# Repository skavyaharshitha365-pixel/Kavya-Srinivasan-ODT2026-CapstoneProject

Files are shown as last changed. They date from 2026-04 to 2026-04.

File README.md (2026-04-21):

Arcade Games

An interactive floor-based arcade gaming system featuring a 3×3 grid of illuminated,
pressure-sensitive tiles synchronized with overhead visual effects. Players engage in four
different games (DDR-style rhythm, Memory sequence, Whack-a-Mole reflexes, and Tic-Tac-Toe
strategy) through physical movement while disco lights, lasers, and mechanical motors create
an immersive atmosphere.

Kavya Harshitha Srinivasan
Awanti Phadke

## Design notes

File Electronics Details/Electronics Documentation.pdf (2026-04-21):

# Electronics Documentation

### 1. Electronics Block Diagram

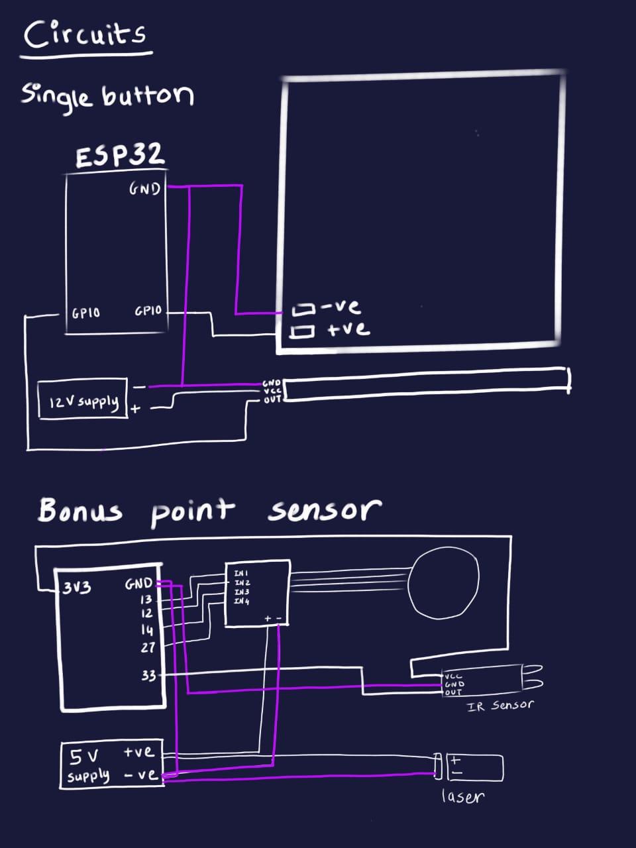
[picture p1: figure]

### 2. Components Table

Component | Quantity | Purpose | Justification
Stepper Motor | 2 | To move the Lasers for hand indications | Complete rotation is required for this application and hence stepper motor
Neopixel Strip | 10 | To give visual cues and feedback on the tiles and set the ambience in overhead disco | Bright multi color lights are required for clear indication for where to step
Laser pointers | 2 | To indicate location of IR sensor and to set the ambience
Bread board | 3
Power module | 2
IR Sensors | 2 | To detect the hands | Small with adjustable range
Copper wire | 10m approx
Electronic Tape | 3m | Hold wires and connections in place and

Power module Adapter | 3
DC Adapter | 2 | Connect 12V neopixel strips

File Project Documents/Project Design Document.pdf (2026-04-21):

## Interactive Arcade System with Physical Tile Grid

## 1. Design Intent

A full-scale arcade installation that transforms digital games into physical experiences. Players step onto a 3×3 grid of illuminated floor tiles, surrounded by overhead disco lighting effects, laser mood lighting and gaming, and motorized visual indicators. Each game (DDR-style rhythm, Memory, Whack-a-Mole, Tic-Tac-Toe) triggers synchronized lighting patterns and motor sequences that match the gameplay intensity and state.

The system creates a gaming experience where every move is reflected in light, color, and motion. Overhead effects telegraph game state to spectators, turning solo gameplay into a shared visual spectacle. The tile buttons have the perfect resistance.

Who is it for?

- Installation/entertainment spaces seeking interactive exhibits
- Maker faires and technology showcases
- Home game rooms with dedicated space
- Interactive museums and science centers
- Event spaces wanting memorable experiences

What problem does it solve?

Reduces the hardware and spacial requirements to have an arcade library.

## 2. Inspiration & References

1. Dance Dance Revolution (DDR) arcade cabinets
2. Memory Game
3. Whack a Mole
4. Tic Tac Toe

Visual References:

- DDR arcade cabinet layout (player positioning, screen placement

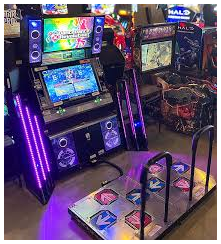
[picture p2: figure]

●

- Laser shows

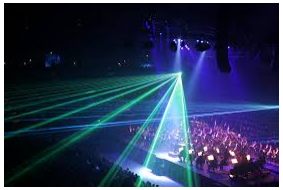
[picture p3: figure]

## 3. User Journey

1. User approaches arcade floor on attract mode
- Overhead disco scrolls pink/purple/blue gradient bands
- Laser-Stepper combos create laser show
- Floor tiles are dark, center tile pulses subtly
2. User steps on CENTER tile
- System wakes up
- Disco shifts to cyan/blue alternating pattern
- Browser displays main menu (DDR selected by default)
- Arrow tiles light up: LEFT/RIGHT to navigate, CENTER to confirm
3. User steps LEFT or RIGHT arrows
- Menu carousel updates

- Disco pattern changes instantly:
■ DDR: cyan/blue swap
■ Memory: orange/warm-orange swap
■ Whack-a-Mole: green-light/green-dark swap ■ Tic-Tac-Toe: magenta/pink-light swap
4. User steps CENTER to confirm
- Instructions are displayed for 5 seconds
- Countdown begins (3...2...1...)
- Disco changes to game-specific pattern
- Tiles light up with game-specific colors
5. Gameplay active (DDR example)
- User steps on lit tiles in rhythm
- Correct step: tile changes color, disco scrolls faster
- Wrong step: both steppers spin opposite directions (0.5s), tile flashes red
- IR beam break: corresponding stepper spins 1 revolution, bonus points awarded
6. Gameplay active (Memory example)
- Watch phase: disco warm/dim pattern, tiles flash sequence
- Play phase: disco scrolls blue/green gradient, user repeats sequence
- Wrong tile: steppers spin opposite, game resets
7. Gameplay active (Whack-a-Mole example)
- Disco scrolls green/cyan/orange/pink/purple/yellow
- Tiles light up randomly
- User steps on lit tile: success feedback, disco continues
- Miss: steppers spin briefly
8. Gameplay active (Tic-Tac-Toe example)
- Player pink vs player purple
- Disco scrolls pink gradient during pink turn
- Disco scrolls purple gradient during purple turn
- Turn change: corresponding stepper spins 1.5 revolutions
9. Game ends — WIN
- Celebration pattern: disco scrolls rainbow at high speed
- Steppers alternate: both CW 2 revs, then both CCW 2 revs (loop)
- End screen displays score
10. Game ends — LOSE
- Failure pattern: disco alternates red/dark-red at slow pulse
- Steppers stop
- End screen displays "Try Again"

11. 60 seconds idle
- System returns to attract mode
- Disco resumes pink/purple/blue scroll
- Steppers resume slow alternating spins

## 4. Success Criteria

Functional Requirements:

Metric | Target | Actual
Tile button response time | <50ms | ~30ms (debounced polling)
NeoPixel frame rate | 50fps (20ms) | 50fps stable
Stepper motor smoothness | No visible stutter | Background thread achieves
Tile button debounce | Prevent double-triggers | 500ms window
IR sensor debounce | Prevent double-triggers | 500ms window
HTTP polling latency | <50ms round-trip | ~30-40ms typical
WiFi reconnection | Automatic recovery | Floor AP stable

Highly durable tile buttons Retains elasticity at 120kg+

| weight | No physical sensor, sturdy flexible materials.

User Experience:

- Color-coded game modes instantly recognizable
- Stepper movements feel intentional, not random
- Disco patterns enhance gameplay without distraction
- Zero visible lag between tile press and visual response
- Error feedback is clear but not punishing
- Game transitions are smooth and predictable

Reliability:

- Motors don't overheat during extended sequences
- WiFi AP handles reconnections gracefully
- System recovers from browser disconnect
- IR sensors work reliably in DDR mode

## 5. System Overview

The system consists of four main components working together:

1. Browser Interface (HTML/JavaScript) - Runs on laptop, displays game UI, contains all game logic (DDR, Memory, Whack-a-Mole, Tic-Tac-Toe), sends tile color commands, receives button presses
2. Bridge Server (IDLE Python on laptop) - HTTP proxy that polls both ESP32 boards, merges 9 floor buttons + 2 ceiling IR sensors into unified 11-element array, routes Neopixels colour and pattern commands to floor and state/event commands to ceiling
3. Floor ESP32 - Hosts WiFi access point, runs HTTP server, reads 9 tile buttons, controls NeoPixels
4. Ceiling ESP32 — Connects to floor's WiFi, runs HTTP server, controls 78-LED disco ring, 2 stepper motors, 2 lasers (always on), 2 IR sensors for DDR bonus detection

Communication flow:

Browser ←→ Bridge ←→ Floor ESP32 (buttons + LEDs) ↓
Ceiling ESP32 (disco + steppers + IR)

All communication is HTTP-based. No WebSocket, no ESPNow. Bridge handles all polling and routing.

## 6. High-Level Block Diagram

## 7. Input / Output Mapping

Input | Process | Output
Tile button press | Floor GPIO detects → Bridge polls /state → Browser game logic | Tile color change via /set_tile → Floor NeoPixels update
Game state change | Browser detects new screen →
Sends
/slave_msg?cmd=S:game:ddr →
| Bridge forwards to ceiling | Ceiling state machine changes → Disco pattern + stepper sequence

IR beam
break (DDR)

Ceiling GPIO detects → Sets sticky flag ir_pressed[0]=1 → Bridge polls /state

Browser bonus handler executes → Sends
/slave_msg?cmd=E:bonus:left:
on → Stepper celebration spin

Wrong
move

Browser game logic detects error → Sends /slave_msg?cmd=E:wrong

Ceiling triggers both steppers opposite directions (0.5s)

DDR speed
increase

Browser tracks tempo → Sends /slave_msg?cmd=D:1.5

Ceiling multiplies disco scroll speed by 1.5×

TTT turn
change

Browser alternates players → Sends /slave_msg?cmd=S:game:ttt:p ink

Ceiling spins left stepper 1 rev (1.5s), disco changes to pink gradient

Win
condition

Browser detects win → Sends /slave_msg?cmd=S:end:win

Ceiling plays celebration pattern (rainbow scroll + alternating spins)

Lose
condition

Browser detects loss → Sends /slave_msg?cmd=S:end:lose

Ceiling plays failure pattern (red pulse + steppers stop)

Menu
navigation

User steps LEFT/RIGHT → Floor button → Bridge → Browser

Browser updates menu → Sends /slave_msg?cmd=S:menu:memory
→ Disco changes to orange pattern

Game
launch

User steps CENTER on menu → Browser confirms → Sends
/slave_msg?cmd=S:game:mole

Ceiling transitions to game pattern, steppers stop

## 8. Sketches & Concepts

Early Concepts:

1. Only DDR as game option
2. Original Architecture
- Master ESP32 ↔ ESPNow ↔ Slave ESP32
- Browser ↔ WebSocket ↔ Master
- Problem: ESPNow debugging difficult, WebSocket adds complexity
- Solution: Bridge-centric HTTP — simpler, more reliable
3. Laser Toggle Indicators
- Lasers originally turned on/off to indicate game events
- Problem: Hardware didn’t support GPIO connection

- Solution: Lasers always ON, rotation through steppers became primary indicators

### 4. Center button choice lock in tic tac toe

- Click center button to lock choice in tic tac toe
- Problem: unintuitive
- Solution: double press the chosen tile

## 9. Final System Architecture

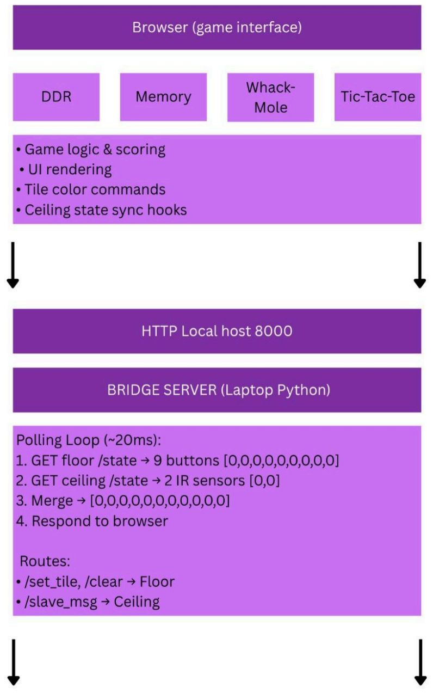
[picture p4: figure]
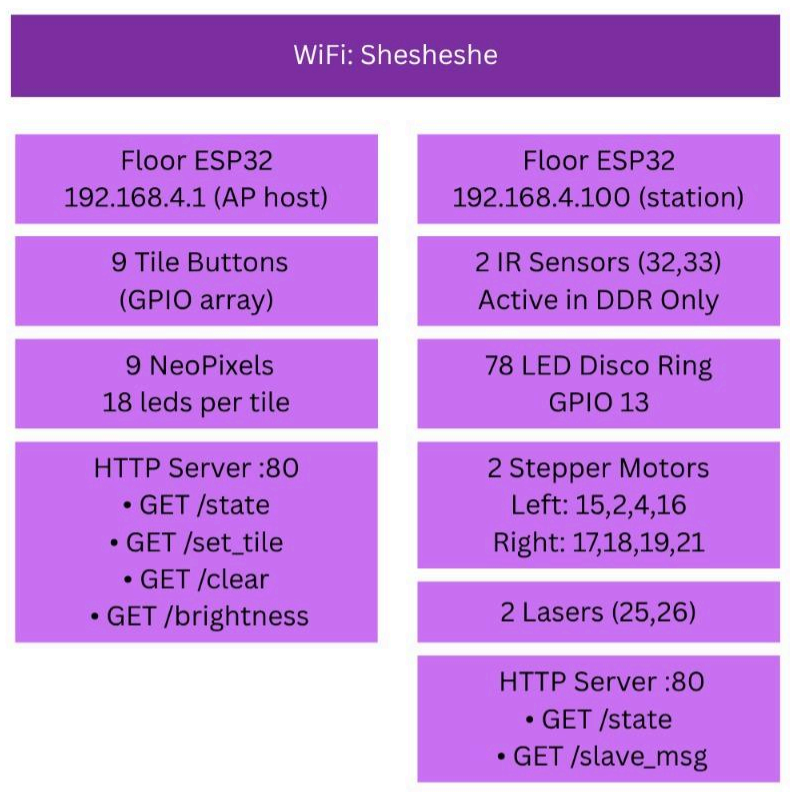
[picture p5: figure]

Power Requirements
FLOOR ESP32:
- ESP32 board: 5V 500mA
- NeoPixels (162 LEDs): 12V
- Recommended: 5V 3A power supply

CEILING ESP32:
- ESP32 board: 5V 500mA
- Disco ring (78 LEDs): 5V 1.5A peak
- Steppers (2×): 5V 500mA (via ULN2003 drivers)
- Lasers (2×): 5V 100mA
- Recommended: 5V 2.5A power supply

Boot Sequence
1. Run Bridge program in IDLE Python → HTTP server on http/localhost:8000
2. Power floor ESP32
→ WiFi AP "Shesheshe" starts
3. Power ceiling ESP32
→ Connects to "Shesheshe"
→ Gets static IP 192.168.4.100
4. Connect laptop to "Shesheshe"
→ Begins polling floor + ceiling
5. Open browser
→ Navigate to http://localhost:8000 → Games load, system ready

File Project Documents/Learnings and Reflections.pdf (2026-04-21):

# Learnings & Reflections

### 1. Team Reflection

- We worked with complementary skills, taking lead in hardware(Awanti) and Software(Kavya) and then further delegating the work.
- What worked well?: Task delegation and Trust among team members for decision making
- What could be improved?: Although task delegation worked some tasks needed to be worked on together that were pushed further.

### 2. Technical Reflection

- Key technical challenges:

Sourcing the materials for a large scale project

working out the connections

interfacing multiple components together

Connecting multiple ESP32

- What did you learn (hardware/software)?

Hardware:

Debugging Soldering and connection issues with the Neopixel strip

Making secure circuits that will not disconnect (Learned our lesson form A1)

Connecting 12 v neopixel strip directly to the power supply adapter

We would test multiple times and if possible in the location of the exhibition one day prior. Time was lost in transporting the model and reconnecting and debugging the connections

ESP32 protects itself and does not run the code if GPIOs are used improperly

Soldering technicalities

Software:

Overcoming ESP limit with python bridge code, as a software architecture solution to a hardware limitation.

Bridge controls both ESP32s, making it easier to De-bug

Connecting across multiple ESP32s

Making wireless independent components connected via wifi.

- Mistakes & debugging experiences

Bugs in micropython code to control our components

Major Malfunction with running of the the code on the exhibition day taught us to think on our feet and display what we have available

### 3. Design Reflection

- Did the experience match your intention?

The Experience matched our intention, with certain exceptions

- Sourcing of materials- Travel expenses and locating applicable vendors
- The neopixel strips- all of them are not working as of the time of this submission, even though it is probably the component we spent the most time debugging
- What would you improve?

Consider technical feasibility right from early ideation

Design floor tiles more specific to leg span and reach of the users on average

The framing of the buttons to make them look as sturdy as they are

Increase clarity of the colours in the interface, to make differentiation easy.

- User feedback insights

We finalised Materials including sponge with the correct density and top layer of buttons according to user feedback about comfort of pressing the button

Although the games in the Arcade matched the speed of our game, Users found the DDR game to be to fast to play. User choices change according to context

Users push the buttons sideways that make them slide

Many users were apprehensive to step on the buttons, being unsure of the sturdyness of the model despite being assured that the model could take force.

### 4. Personal Reflection

Kavya

- What they learned:

We tried to be as inclusive as possible, but still ended up excluding a few users that lie of the extremes of height.

People are apprehensive of stepping on the times, afraid that they might break it

People wanted to dance but did not do it, in order to be modest

- What they struggled with

Tries to think in a linear manner and got stuck on a step when I could have worked in a non-linear style

Blaming myself with things that were out of my hands

Expenses went overboard

- What they are proud of

Solving a LOT of problems and gaining Knowledge along the way

Finding innovative solutions

My teammate for the buttons

Finding a solution to the material problems with research and prototyping

Awanti

- What they learned:

Time management,

Testing, debugging of hardware and software

Problem solving and finding innovative solutions through prototyping

Finding workarounds to component sourcing constraints

- What they struggled with

Consistently motivating myself when tests were failing

I am learning coding for the first time and struggled to keep up with the speed and complexity we needed to work with

Planning in advance for sourcing and testing of components: We faced issues with unnecessary expenses due to wrong or malfunctioning components. Some of these could be avoided with more efficient planning

- What they are proud of

We tried to do something big and worked hard for it even though it was difficult

The Problem solving and iterations

Smooth functioning of the buttons and game floor

The interface of the project

Overcoming Material and component sourcing constraints

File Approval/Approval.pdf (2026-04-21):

# ARCADE TILE GRID SYSTEM

## Project Overview

An interactive floor-based arcade gaming system featuring a 3×3 grid of illuminated, pressure-sensitive tiles synchronized with overhead visual effects. Players engage in four different games (DDR-style rhythm, Memory sequence, Whack-a-Mole reflexes, and Tic-Tac-Toe strategy) through physical movement while disco lights, lasers, and mechanical motors create an immersive atmosphere.

Project Type | Interactive Gaming Installation
Grid Size | 3×3 tiles (9 interactive zones)

Total NeoPixel LEDs 18 x 9 = 162 (tile) + 78 (overhead)
| addressable RGB LEDs
Games Included | 4 (DDR, Memory, Whack-a-Mole, Tic-Tac-Toe)
Players | 1-2 simultaneous
Control Method | Physical tile presses + browser interface
Response Time | < 50ms tile-to-LED feedback

## Core Features

### 1. Multi-Game Platform

- Memory Challenge — Watch and reproduce increasingly complex tile sequences (3 difficulty levels)
- Whack-a-Mole — Hit glowing tiles before they disappear (speed increases over time)
- Tic-Tac-Toe — Two-player strategic game with 20-second turn timers
- DDR (Dance Dance Revolution) — Rhythm-based gameplay with bonus collection zones

### 2. Synchronized Visual Effects

- 162 Tile NeoPixel LEDs — Each tile has 18 individually controlled RGB LEDs (8 directional arrows + center octagon)
- 78 Overhead Disco LEDs — Circular ring creates ambient patterns matching game state
- 2 Laser Pointers — Constant ambient lighting (650nm red, always on)
- 15+ Pattern Modes — Attract screen, menu browsing, gameplay states, win/lose animations

### 3. Mechanical Feedback

- 2 Stepper Motors — Visual indicators replacing traditional laser on/off (used for turn changes, bonus collection, wrong moves)
- 2 IR Beam-Break Sensors — Detect DDR bonus collection (player breaks infrared beam)
- Choreographed Sequences — Motors spin in sync with game events (attract dance, celebration spins)

### 4. Wireless Architecture

- WiFi Access Point — Browser connects directly to arcade (no internet needed)
- Distributed Processing — computer handles frontend visuals and communication bridging, microprocessors act as server and control hardware.

## Technical Highlights

Performance

- 50 FPS pattern refresh rate on disco ring
- 500 FPS main loop on ESP32 (tile detection)

Smart Architecture

- Interrupt-Driven Buttons — Zero polling overhead, instant response
- Background Stepper Thread — Motors run independently without blocking LED updates
- Stateless Browser — Game logic in HTML/JS allows easy updates without reflashing hardware
- Pattern Engine — 15+ pre-compiled color palettes (no runtime color calculations)

Reliability

- Software Debouncing — 150ms tile buttons, 500ms IR sensors (prevents double-triggers)
- Error Tolerance — System continues operating if one component fails
- Score displayed on browser
- Returns to attract after 20 seconds

## Concept Sketch

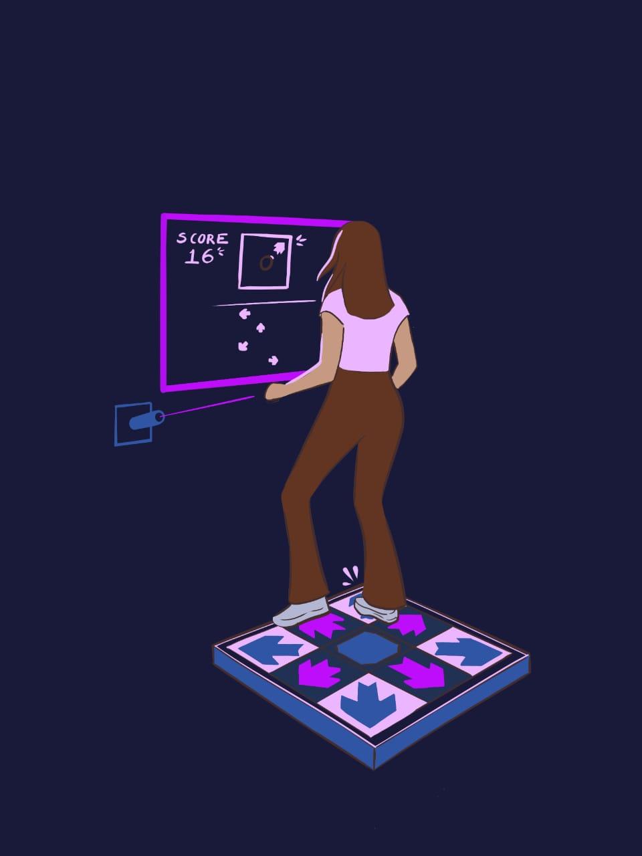
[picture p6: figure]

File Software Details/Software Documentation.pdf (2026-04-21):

# Software Documentation

### 1. Software Overview

The arcade system software transforms a 3×3 grid of physical floor tiles into an immersive, full-body gaming platform. The software coordinates four major subsystems working in real-time: floor tile monitoring and LED control, overhead visual effects (disco lighting, stepper motors, lasers), game logic processing (DDR, Memory, Whack-a-Mole, Tic-Tac-Toe), and a central communication bridge that unifies all components. When a player steps on a tile, the software detects the input, executes game rules in the browser, updates floor LEDs with color-coded feedback, and simultaneously triggers synchronized ceiling effects including dynamic light patterns and motor choreography. The system uses HTTP polling architecture where a laptop-based bridge server continuously queries both ESP32 microcontrollers , merges button states from 9 tiles and 2 IR sensors into a unified 11-element array, and routes commands bidirectionally between the web-based game interface and embedded hardware. This creates a seamless experience where digital game logic controls physical outputs while physical inputs drive game progression. The result is an arcade experience where players interact naturally through movement while spectators enjoy the synchronized light show.

Component | Platform | Purpose
Floor ESP32 | MicroPython | Button polling, NeoPixel control, WiFi AP hosting
Ceiling ESP32 | MicroPython | Disco patterns, stepper sequences, IR sensing, state machine
Bridge Server | Python 3 (IDLE Python) | HTTP proxy, button merging, command routing
Game Interface | HTML/JavaScript | Game logic, UI rendering, hardware sync hooks

### 2. System Logic

User Input Flow : User steps → Floor detects → Bridge polls → Merges buttons → Browser receives → Game logic → LED command → Floor updates → Visual feedback

Game State Flow (10 steps): Menu navigation → State command → Bridge forwards → Ceiling receives → State machine → Disco pattern change → User sees overhead effect

IR Sensor Flow (12 steps): Hand waves → IR triggers → Sticky flag → Stepper feedback → Bridge polls → Browser awards points → Celebration spin

Wrong Move Flow (9 steps): Wrong tile → Game detects → Flash red → Error event → Motors spin opposite → User sees/hears → Game continues

### Technical Implementation Details

Timing Specifications

- • Bridge polling cycle: ~20ms (50Hz)
- • NeoPixel frame rate: 20ms (50fps)
- • Button debounce: 50ms window
- • IR sensor debounce: 500ms window
- • Button press to LED update: <50ms total latency
- • State change to disco pattern: <100ms
- • Stepper motor delay: 800-1200µs per step

Error Handling

- • Floor timeout: 1 second → Retry once, then fail gracefully
- • Ceiling timeout: 0.5 seconds → Return zeros, floor still works
- • WiFi disconnect: Floor auto-reconnects, bridge waits
- • Invalid command: Ignored silently, system continues
- • Button state conflict: Bridge uses most recent poll
- • NeoPixel buffer overflow: Clamped to array bounds

### 3. Flowchart

Visual representation of logic

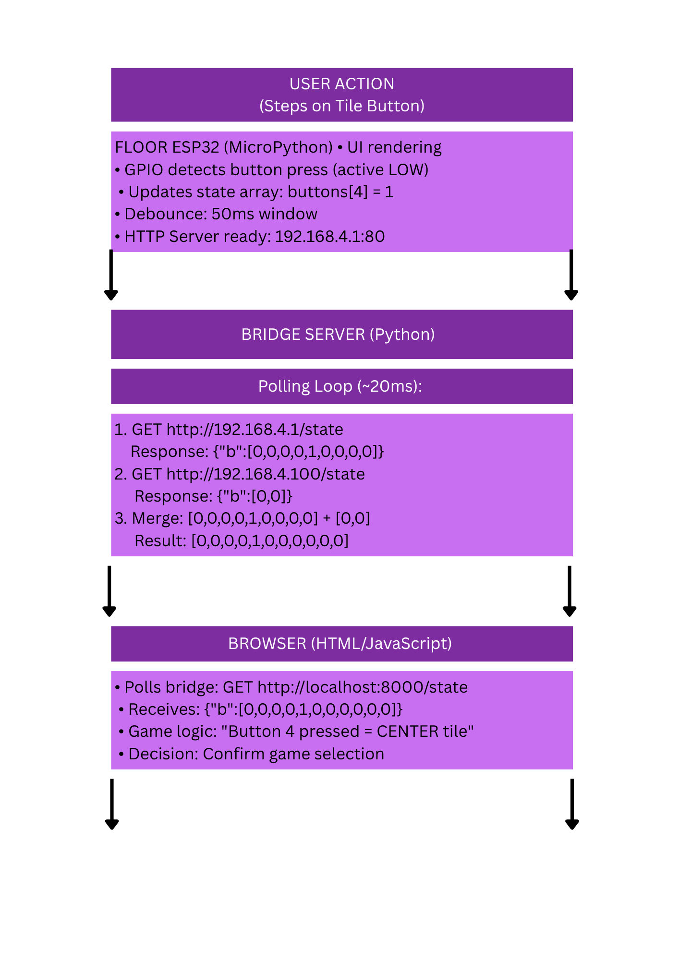
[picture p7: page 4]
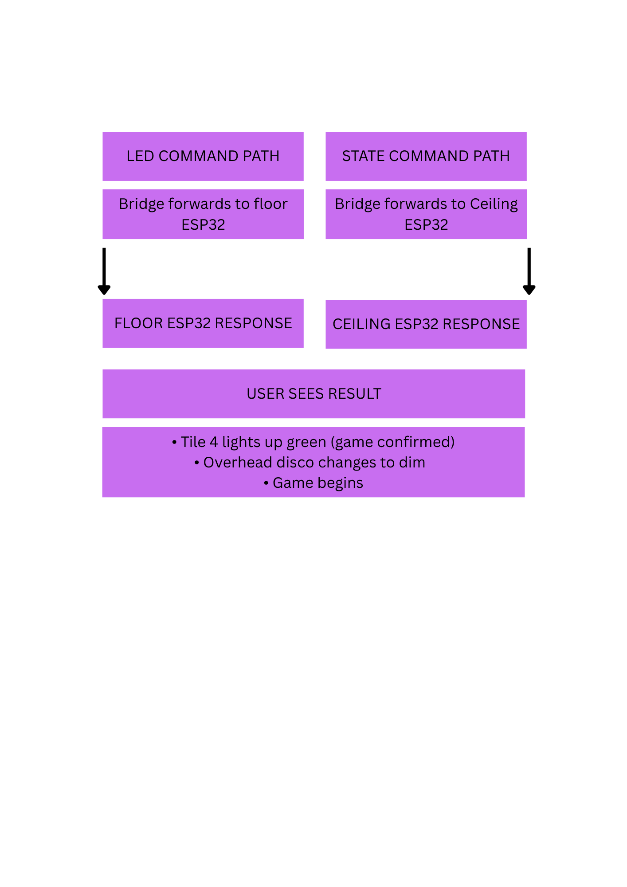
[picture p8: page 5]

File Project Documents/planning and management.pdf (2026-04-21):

# Project Planning & Management Document

### 1. Project Overview

An interactive floor-based arcade gaming system featuring a 3×3 grid of illuminated, pressure-sensitive tiles synchronized with overhead visual effects. Players engage in four different games (DDR-style rhythm, Memory sequence, Whack-a-Mole reflexes, and Tic-Tac-Toe strategy) through physical movement while disco lights, lasers, and mechanical motors create an immersive atmosphere.

### 2. Team Roles & Responsibilities

Member Name | Role | Responsibilities
Awanti | Physical Structure and circuitry planning | Planning and execution of prototype and final structure
| | Writing assigned sections of code
Kavya | Code and interface planning | Planning and execution of interface and Code
| | Building assigned sections of prototype
Task | Subtask | Distribution | Due Date

Concept Note | | Kavya | 4 April
Circuit diagram | | Awanti | 4 April
Prototyping | electronics+code | Both
| Physical tile | Both
Coding | | Awanti
| | Kavya
Interface with wifi | | Kavya
Final Build | Structure | both
| Adding electronics | both
| testing | both

### 3. Project Timeline & Milestones

Week | Goals | Deliverables | Status
Week 0 | Brainstorm and finalise concept | Concept note | done
| | Concept sketches | done
| | basic prototype and material testing | done
| | Basic interface and code | done
Week 1 | First prototype | Single working floor button | done
| | Code and Interface | done
| | Finalise and order all required components | done

Week 2 | Buying and testing components | Buying components from ulhasnagar shop | done
| | Buying extra Copper wire | done
| | Testing all components | done
| Final circuit and code | Test code | done
| | Test circuits | done
| | Interface and test together | done

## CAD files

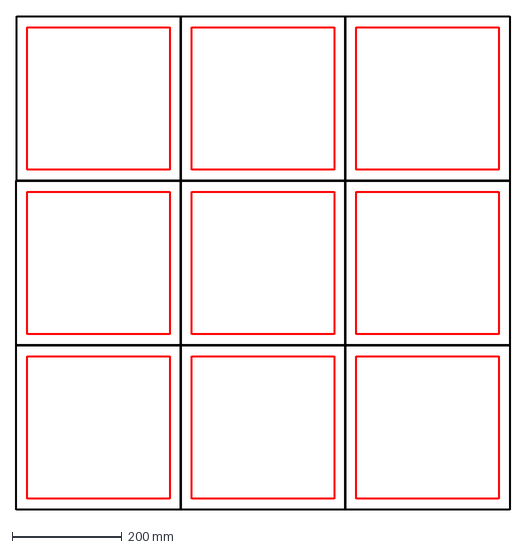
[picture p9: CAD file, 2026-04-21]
Mechanical Details/Fabrication ODT Final MDF Laser cut.dxf
900.0 x 900.0 mm

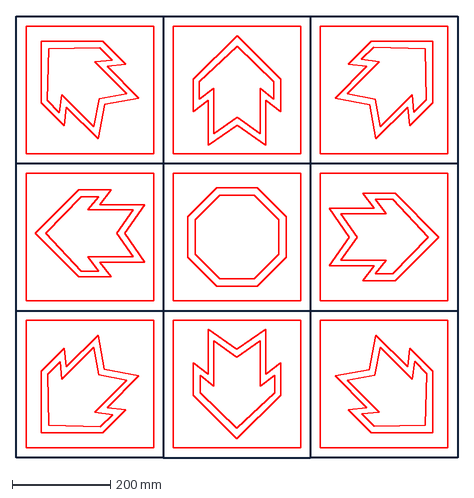
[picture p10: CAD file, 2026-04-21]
Mechanical Details/Fabrication PVC Sheet Final Laser cut.dxf
900.3 x 900.0 mm

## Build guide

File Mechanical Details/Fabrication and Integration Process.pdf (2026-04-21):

# Fabrication and Integration Process

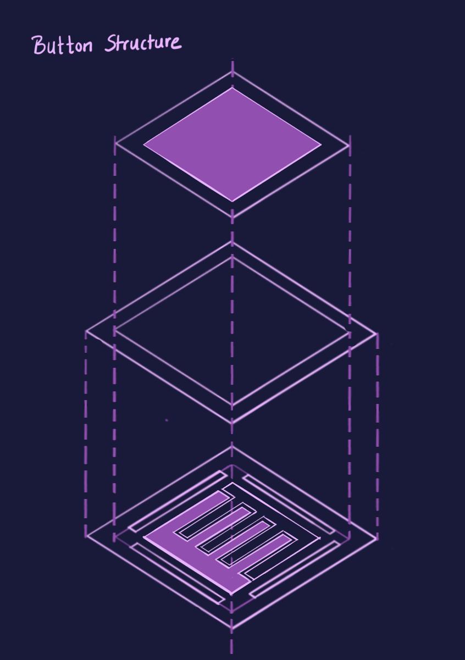
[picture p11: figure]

### 1. Material Choice Justification :

Why choose Transparent PVC Flexible Sheet over Acrylic?

Transparent PVC sheets are preferred over acrylic when flexibility, safety, and tactile comfort are important.

- Impact Resistance: PVC is elastic—it absorbs impact and deforms without cracking, unlike acrylic which is brittle and prone to fracture.
- Flexibility: PVC can bend and return to shape, making it suitable for dynamic or load-bearing interactions.
- Safety: No sharp breakage → safer in high-contact or foot-based applications.
- Tactile Quality: Slightly soft underfoot, improving comfort and user experience.
- Functional Aesthetic: Maintains transparency like acrylic but introduces a more adaptive, responsive visual language rather than rigid perfection.

Why choose MDF over Metal?

MDF is chosen over metal when controlled flexibility, ease of fabrication, and surface finish matter.

- Elastic Behavior (to an extent): MDF can slightly flex under load and return, whereas metal either resists completely or deforms permanently.
- Workability: Easy to cut, drill, shape, and prototype - ideal for iterative design.
- Surface Quality: Smooth, uniform surface but enough texture to paint on.
- Cost & Accessibility: More economical and accessible for prototyping and small-scale production.

Why Sponge instead of Spring?

Sponge (foam) is preferred over springs when uniform comfort and long-term performance are key.

- Even Weight Distribution: Foam spreads load across the surface, avoiding pressure points (springs localize force).
- Consistent Elasticity: Provides uniform compression and recovery rather than point-based bounce.
- Durability: High-quality foam maintains elasticity over time without mechanical fatigue typical in springs.
- Impact Absorption: Better at damping sudden forces—more controlled, less rebound.
- User Comfort: Feels stable and supportive rather than bouncy or uneven.
Material Choice | Justification
Medium Density Fiberboard | Uniform structure (evenly distributed strength across material)
| Flexibility (Bends rather than break, with the amount of force we are putting on it)
Sponge | Elasticity (springs back to original shape)

Structural Integrity (hold its structure unless compressed)

Transparent PVC Flexible Sheet 5mm | Fully transparent but bends light at cuts
| Elastic - can take impact without cracking
| Soft feel on the feet

### 2. Fabrication Steps :

1. Laser cut 1sq.ft mdf squares x 18
2. Laser cut 1sq.ft transparent PVC squares with tile design x 9
3. Add paper tape to aluminum foil to strengthen
4. Cut foil into negative and positive terminal of the button
5. Wiring the buttons
6. Adding sponge and top connector foil to the button
7. Fix buttons to base made from foam board
8. Secure wiring to board to avoid loose connections

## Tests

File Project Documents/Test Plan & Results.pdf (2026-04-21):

# Test Plan & Results

### 1. Test Plan

Test type | Test | Method | Expected Result
Material choice and fabrication | durability and tactile button feel | Step on button made from MDF and cardboard/foam inserts with considerable force | MDF with foam cushioning will perform as the best button
Circuit Completion System | Durability of foil, ensuring circuit completion and prevent short circuit | Try methods of foil backing and wire connection that are sucure

### 2. User Testing

1:
Who: Classmates from our section
Task: Step on button made from MDF and cardboard/foam inserts with considerable force

2:
Who: Classmates and professors
Task: Play the game and evaluate the speed and difficulty

### 3. Results

Test | Outcome | Pass/Fail

1 Mdf does not Break under force or repeated use | with shoes | Pass
| Both negative and positive terminals on the ground with the button itself acting as a connector, with wires attached with Foil on top and electrical tape works best | Pass
2 The original speed and difficulty were too high and | were fixed

### 4. Observations

Users preferred foam buttons over cardboard

Users prefer games of medium difficulty, just challenging enough.

### 6. Improvements Suggested

- Slow down the pace of the game

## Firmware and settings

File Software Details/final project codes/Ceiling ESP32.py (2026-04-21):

#main ceiling
from machine import Pin
from neopixel import NeoPixel
from time import sleep_ms, sleep_us, ticks_ms, ticks_us, ticks_diff, ticks_add
import network
import socket
import time
import _thread

LEFT_STEP_PINS  = [15, 4, 5, 18]
RIGHT_STEP_PINS = [19, 21, 22, 23]

C = {'off':          (0, 0, 0),
    'white':        (255, 255, 255),
    'red':          (255, 0, 0),
    'red_dark':     (100, 0, 0),
    'pink':         (255, 45, 122),
    'pink_light':   (255, 150, 180),
    'pink_hot':     (255, 80, 150),
    'pink_deep':    (200, 30, 90),
    'pink_soft':    (255, 120, 180),
    'pink_rose':    (255, 60, 130),
    'magenta':      (255, 0, 200),
    'purple':       (192, 64, 255),
    'purple_dark':  (140, 40, 200),
    'purple_deep':  (100, 20, 160),
    'purple_mid':   (160, 50, 220),
    'purple_light': (220, 80, 255),
    'purple_plum':  (120, 30, 180),
    'blue_dark':    (0, 0, 139),
    'blue_light':   (100, 180, 255),
    'blue_mid':     (0, 0, 140),
    'cyan':         (0, 255, 255),
    'green_light':  (100, 255, 100),
    'green_dark':   (0, 80, 10),
    'green_bright': (80, 255, 120),
    'green_lime':   (57, 255, 20),
    'orange':       (255, 165, 0),
    'orange_warm':  (200, 120, 0),
    'orange_bright':(255, 140, 0),
    'yellow':       (255, 230, 0),
    'warm':         (255, 180, 80),
    'warm_dim':     (180, 120, 50)}

disco = NeoPixel(Pin(DISCO_PIN), 78)

left_ir = Pin(3, Pin.IN, Pin.PULL_UP)
right_ir = Pin(16, Pin.IN, Pin.PULL_UP)

for i in range(DISCO_COUNT):
    disco[i] = C['off']
disco.write()

STEP_SEQ = [[1, 0, 0, 1], [1, 0, 0, 0], [1, 1, 0, 0], [0, 1, 0, 0],[0, 1, 1, 0], [0, 0, 1, 0], [0, 0, 1, 1], [0, 0, 0, 1]]
STEPS_PER_REV = 4096

left_pins  = [Pin(p, Pin.OUT) for p in LEFT_STEP_PINS]
right_pins = [Pin(p, Pin.OUT) for p in RIGHT_STEP_PINS]

left_pos = 0
left_target = 0
left_delay_us = 1200
left_step_idx = 0

right_pos = 0
right_target = 0
right_delay_us = 1200
right_step_idx = 0

def spin_cw(motor, revs, duration):
    global left_target, left_delay_us, right_target, right_delay_us
    steps = int(revs * STEPS_PER_REV)
    if steps == 0:
        return
    delay = max(800, int((duration * 1_000_000) / abs(steps)))
    if motor == 'left':
        left_target = left_pos + steps
        left_delay_us = delay
    else:
        right_target = right_pos + steps
        right_delay_us = delay

def spin_ccw(motor, revs, duration):
    global left_target, left_delay_us, right_target, right_delay_us
    steps = int(revs * STEPS_PER_REV)
    if steps == 0:
        return
    delay = max(800, int((duration * 1_000_000) / abs(steps)))
    if motor == 'left':
        left_target = left_pos - steps
        left_delay_us = delay
    else:
        right_target = right_pos - steps
        right_delay_us = delay

def stop_motor(motor):
    global left_target, right_target
    if motor == 'left':
        left_target = left_pos
        for p in left_pins: p.value(0)
    else:
        right_target = right_pos
        for p in right_pins: p.value(0)

def stop_all_motors():
    stop_motor('left')
    stop_motor('right')

def stepper_thread():
    global left_pos, left_step_idx, right_pos, right_step_idx
    left_next = ticks_us()
    right_next = ticks_us()
    
    while True:
        now = ticks_us()
        if left_pos != left_target:
            if ticks_diff(now, left_next) >= 0:
                d = 1 if left_target > left_pos else -1
                left_pos += d
                left_step_idx = (left_step_idx + d) % 8
                seq = STEP_SEQ[left_step_idx]
                for i in range(4): left_pins[i].value(seq[i])
                left_next = ticks_add(now, left_delay_us)
        else:
            for p in left_pins: p.value(0)

        if right_pos != right_target:
            if ticks_diff(now, right_next) >= 0:
                d = 1 if right_target > right_pos else -1
                right_pos += d
                right_step_idx = (right_step_idx + d) % 8
                seq = STEP_SEQ[right_step_idx]
                for i in range(4): right_pins[i].value(seq[i])
                right_next = ticks_add(now, right_delay_us)
        else:
            for p in right_pins: p.value(0)

        sleep_us(200)

_thread.start_new_thread(stepper_thread, ())
print("Stepper thread running")

seq_cmds = []
seq_idx = 0
seq_start = 0
seq_dur = 0
seq_loop = False
seq_on = False

def set_sequence(cmds, loop=False):
    global seq_cmds, seq_idx, seq_start, seq_loop, seq_on
    seq_cmds = cmds
    seq_idx = 0
    seq_loop = loop
    seq_on = True
    seq_start = ticks_ms()
    _run_seq_step()

def stop_sequence():
    global seq_on
    seq_on = False
    stop_all_motors()

def _run_seq_step():
    global seq_dur
    if seq_idx >= len(seq_cmds):
        return
    cmd = seq_cmds[seq_idx]

    if cmd[0] == 'cw':
        spin_cw(cmd[1], cmd[2], cmd[3])
        seq_dur = int(cmd[3] * 1000)
    elif cmd[0] == 'ccw':
        spin_ccw(cmd[1], cmd[2], cmd[3])
        seq_dur = int(cmd[3] * 1000)
    elif cmd[0] == 'both':
        fn_l = spin_cw if cmd[1] == 'cw' else spin_ccw
        fn_r = spin_cw if cmd[3] == 'cw' else spin_ccw
        fn_l('left', cmd[2], cmd[5])
        fn_r('right', cmd[4], cmd[5])
        seq_dur = int(cmd[5] * 1000)
    elif cmd[0] == 'wait':
        seq_dur = int(cmd[1] * 1000)
    elif cmd[0] == 'stop':
        stop_all_motors()
        seq_dur = 0

def update_sequence():
    global seq_idx, seq_start, seq_on
    if not seq_on or not seq_cmds:
        return
    if ticks_diff(ticks_ms(), seq_start) >= seq_dur:
        seq_idx += 1
        if seq_idx >= len(seq_cmds):
            if seq_loop:
                seq_idx = 0
            else:
                seq_on = False
                return
        seq_start = ticks_ms()
        _run_seq_step()

sta = network.WLAN(network.STA_IF)
sta.active(True)
sta.disconnect()

WIFI_SSID = 'Shesheshe'
WIFI_PASS = '12345678'

print("Connecting to WiFi:", WIFI_SSID)
sta.connect(WIFI_SSID, WIFI_PASS)

for _ in range(30):
    if sta.isconnected():
        break
    time.sleep(0.5)

if sta.isconnected():
    print("WiFi connected!")
    print("Ceiling IP:", sta.ifconfig()[0])
else:
    print("WiFi FAILED — rebooting in 5s")
    time.sleep(5)
    import machine
    machine.reset()

ir_left_last = 0
ir_right_last = 0
IR_DEBOUNCE = 500
ir_active = False

ir_left_triggered = 0
ir_right_triggered = 0

def check_ir_sensors():
    global ir_left_last, ir_right_last
    global ir_left_triggered, ir_right_triggered
    if not ir_active:
        return
    now = ticks_ms()

    if left_ir.value() == 0 and ticks_diff(now, ir_left_last) > IR_DEBOUNCE:
        ir_left_last = now
        ir_left_triggered = 1
        spin_cw('left', 1, 1.0)
        print("Left IR — bonus!")

    if right_ir.value() == 0 and ticks_diff(now, ir_right_last) > IR_DEBOUNCE:
        ir_right_last = now
        ir_right_triggered = 1
        spin_cw('right', 1, 1.0)
        print("Right IR — bonus!")

ATTRACT_PAT  = [C['pink'], C['pink'], C['purple'], C['purple'], C['blue_dark'], C['blue_dark']]
MENU_DDR_PAT = [C['cyan'], C['blue_dark']]
MENU_MEM_PAT = [C['orange'], C['orange_warm']]
MENU_MOLE_PAT= [C['green_light'], C['green_dark']]
MENU_TTT_PAT = [C['magenta'], C['pink_light']]
DDR_PAT      = [C['pink'], C['pink'], C['orange_bright'], C['orange_bright'], C['yellow'], C['yellow']]
MEM_PLAY_PAT = [C['blue_light'], C['blue_light'], C['blue_light'], C['blue_mid'], C['blue_mid'], C['blue_mid'], C['green_bright'], C['green_bright'], C['green_bright']]
MOLE_PAT     = [C['green_lime'], C['cyan'], C['orange'], C['pink'], C['purple'], C['yellow']]
TTT_PINK_PAT = [C['pink'], C['pink_hot'], C['pink_soft'], C['pink_deep'], C['pink_rose'], C['pink_light']]
TTT_PURP_PAT = [C['purple'], C['purple_dark'], C['purple_deep'], C['purple_mid'], C['purple_light'], C['purple_plum']]
WIN_PAT      = [C['pink'], C['cyan'], C['yellow'], C['green_lime'], C['purple'], C['orange']]

def disco_off():
    for i in range(DISCO_COUNT):
        disco[i] = C['off']
    disco.write()

def _scroll(t, speed_ms, pat):
    offset = (t // speed_ms) % DISCO_COUNT
    n = len(pat)
    for i in range(DISCO_COUNT):
        disco[i] = pat[(i + offset) % n]
    disco.write()

def _swap(t, interval_ms, c1, c2):
    swap = (t // interval_ms) % 2
    for i in range(DISCO_COUNT):
        disco[i] = c1 if ((i % 2) == swap) else c2
    disco.write()

def pattern_attract(t):
    _scroll(t, 40, ATTRACT_PAT)

def pattern_menu_ddr(t):
    _swap(t, 500, C['cyan'], C['blue_dark'])

def pattern_menu_memory(t):
    _swap(t, 500, C['orange'], C['orange_warm'])

def pattern_menu_mole(t):
    _swap(t, 500, C['green_light'], C['green_dark'])

def pattern_menu_ttt(t):
    _swap(t, 500, C['magenta'], C['pink_light'])

def pattern_game_ddr(t, speed):
    scroll_ms = max(10, int(60 / speed))
    _scroll(t, scroll_ms, DDR_PAT)

def pattern_memory_watch(t):
    for i in range(DISCO_COUNT):
        disco[i] = C['warm'] if (i % 3 == 0) else C['warm_dim']
    disco.write()

def pattern_memory_play(t):
    _scroll(t, 1000, MEM_PLAY_PAT)

def pattern_game_mole(t):
    offset = (t // 25) % DISCO_COUNT
    n = len(MOLE_PAT)
    for i in range(DISCO_COUNT):
        pos = (i + offset) % DISCO_COUNT
        disco[i] = MOLE_PAT[(pos // 3) % n] if (pos % 3 == 0) else C['off']
    disco.write()

def pattern_ttt_pink(t):
    _scroll(t, 1000, TTT_PINK_PAT)

def pattern_ttt_purple(t):
    _scroll(t, 1000, TTT_PURP_PAT)

def pattern_win(t):
    _scroll(t, 15, WIN_PAT)

def pattern_lose(t):
    _swap(t, 800, C['red'], C['red_dark'])

state = 'off'
speed_mult = 1.0

def change_state(new_state):
    global state, ir_active
    if new_state == state:
        return
    print("State:", state, "->", new_state)
    state = new_state

    if state == 'attract':
        set_sequence([
            ('both', 'cw', 3, 'ccw', 3, 6.0),
            ('wait', 0.5),
            ('both', 'ccw', 3, 'cw', 3, 6.0),
            ('wait', 0.5),
        ], loop=True)
        ir_active = False

    elif state.startswith('menu_'):
        stop_sequence()
        ir_active = False

    elif state == 'game_ddr':
        stop_sequence()
        ir_active = True

    elif state == 'mem_watch':
        stop_sequence()
        ir_active = False

    elif state == 'mem_play':
        ir_active = False

    elif state == 'game_mole':
        stop_sequence()
        ir_active = False

    elif state == 'ttt_pink':
        stop_sequence()
        spin_cw('left', 1, 1.5)
        ir_active = False

    elif state == 'ttt_purple':
        stop_sequence()
        spin_cw('right', 1, 1.5)
        ir_active = False

    elif state == 'win':
        set_sequence([
            ('both', 'cw', 2, 'ccw', 2, 2.0),
            ('both', 'ccw', 2, 'cw', 2, 2.0),
        ], loop=True)
        ir_active = False

    elif state == 'lose':
        stop_sequence()
        ir_active = False

    elif state == 'off':
        stop_sequence()
        disco_off()
        ir_active = False

def send_response(conn, status, ctype, body):
    conn.send("HTTP/1.1 {} OK\r\n".format(status))
    conn.send("Content-Type: {}\r\n".format(ctype))
    conn.send("Access-Control-Allow-Origin: *\r\n")
    conn.send("Cache-Control: no-store\r\n")
    conn.send("Connection: close\r\n\r\n")
    conn.sendall(body)

def parse_params(url):
    if '?' not in url:
        return {}
    qs = url.split('?')[1].split(' ')[0]
    params = {}
    for pair in qs.split('&'):
        if '=' in pair:
            k, v = pair.split('=', 1)
            params[k] = v
    return params


addr = socket.getaddrinfo('0.0.0.0', 80)[0][-1]
server = socket.socket()
server.setsockopt(socket.SOL_SOCKET, socket.SO_REUSEADDR, 1)
server.bind(addr)
server.listen(5)

print("HTTP server running on :80")

FRAME_MS = 20

print("Ceiling ready")
change_state('attract')

while True:
    frame_start = ticks_ms()

    try:
        server.setblocking(False)
        conn, _ = server.accept()
        server.setblocking(True)
        try:
            request = conn.recv(1024).decode('utf-8', 'ignore')
            first_line = request.split('\r\n')[0] if request else ''
            url_path = first_line.split(' ')[1] if ' ' in first_line else ''

            if 'GET /ir_state' in first_line:
                payload = '{{"ir":[{},{}]}}'.format(
                    ir_left_triggered, ir_right_triggered)
                send_response(conn, 200, 'application/json', payload)
                ir_left_triggered = 0
                ir_right_triggered = 0

            elif 'GET /set_state' in first_line:
                p = parse_params(url_path)
                new_state = p.get('state', '')
                if new_state:
                    change_state(new_state)
                    send_response(conn, 200, 'text/plain', 'OK')
                else:
                    send_response(conn, 400, 'text/plain', 'NEED_STATE')

            elif 'GET /event' in first_line:
                p = parse_params(url_path)
                event = p.get('type', '')
                if event == 'wrong':
                    spin_cw('left', 1, 0.5)
                    spin_ccw('right', 1, 0.5)
                elif event == 'bonus_left':
                    spin_cw('left', 2, 1.5)
                elif event == 'bonus_right':
                    spin_ccw('right', 2, 1.5)
                send_response(conn, 200, 'text/plain', 'OK')

            elif 'GET /speed' in first_line:
                p = parse_params(url_path)
                try:
                    speed_mult = float(p.get('value', speed_mult))
                    send_response(conn, 200, 'text/plain', 'OK')
                except:
                    send_response(conn, 400, 'text/plain', 'BAD')
            else:
                send_response(conn, 200, 'text/plain', 'CEILING ESP32 OK')
        except Exception as e:
            print("[ERR]", e)
        finally:
            conn.close()

    except OSError:
        pass

    check_ir_sensors()
    t = ticks_ms()
    if   state == 'attract':      pattern_attract(t)
    elif state == 'menu_ddr':     pattern_menu_ddr(t)
    elif state == 'menu_memory':  pattern_menu_memory(t)
    elif state == 'menu_mole':    pattern_menu_mole(t)
    elif state == 'menu_ttt':     pattern_menu_ttt(t)
    elif state == 'game_ddr':     pattern_game_ddr(t, speed_mult)
    elif state == 'mem_watch':    pattern_memory_watch(t)
    elif state == 'mem_play':     pattern_memory_play(t)
    elif state == 'game_mole':    pattern_game_mole(t)
    elif state == 'ttt_pink':     pattern_ttt_pink(t)
    elif state == 'ttt_purple':   pattern_ttt_purple(t)
    elif state == 'win':          pattern_win(t)
    elif state == 'lose':         pattern_lose(t)

    update_sequence()

    elapsed = ticks_diff(ticks_ms(), frame_start)
    if elapsed < FRAME_MS:
        sleep_ms(FRAME_MS - elapsed)

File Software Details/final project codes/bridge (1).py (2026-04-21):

import http.server
import urllib.request
import urllib.error
import json
import os
import sys
import threading
import time

# ============================================================
#  CONFIGURATION
# ============================================================

# Floor ESP32 — WiFi access point, always at this IP
FLOOR_IP   = "192.168.4.1"
FLOOR_PORT = 80

# Ceiling ESP32 — connects to Floor AP, IP assigned by DHCP
# Typically 192.168.4.2, but we auto-discover to be safe
CEILING_IP   = None   # set by auto-discovery
CEILING_PORT = 80

# Bridge server port (your browser connects here)
BRIDGE_PORT = 8000

# Path to your HTML file
HTML_FILE = "finalwebcode.html"


# ============================================================
#  CEILING AUTO-DISCOVERY
# ============================================================
#
# The ceiling ESP32 gets a DHCP address from the floor AP.
# We scan the small subnet to find it.
#

def discover_ceiling(timeout=1.0):
    """Try common DHCP addresses to find the ceiling ESP32."""
    candidates = [
        "192.168.4.2",
        "192.168.4.3",
        "192.168.4.4",
        "192.168.4.5",
    ]
    for ip in candidates:
        try:
            url = "http://{}:{}/".format(ip, CEILING_PORT)
            req = urllib.request.Request(url)
            req.add_header('Connection', 'close')
            with urllib.request.urlopen(req, timeout=timeout) as resp:
                body = resp.read().decode('utf-8', 'ignore')
                if 'CEILING' in body:
                    return ip
        except:
            pass
    return None


def discover_ceiling_loop():
    """Background thread: keep trying until ceiling is found."""
    global CEILING_IP
    while CEILING_IP is None:
        ip = discover_ceiling()
        if ip:
            CEILING_IP = ip
            print("[BRIDGE] Ceiling ESP32 found at {}".format(ip))
        else:
            time.sleep(2)


# ============================================================
#  CACHED CEILING IR STATE
# ============================================================
#
# The bridge polls the ceiling ESP32 for IR sensor triggers
# in a background thread so the main /state response is fast.
#

ceiling_ir = [0, 0]          # latest IR trigger flags
ceiling_lock = threading.Lock()
ceiling_alive = False


def ceiling_poll_loop():
    """Background thread: poll ceiling /ir_state every ~80ms."""
    global ceiling_ir, ceiling_alive
    while True:
        if CEILING_IP is None:
            time.sleep(0.5)
            continue
        try:
            url = "http://{}:{}/ir_state".format(CEILING_IP, CEILING_PORT)
            req = urllib.request.Request(url)
            req.add_header('Connection', 'close')
            with urllib.request.urlopen(req, timeout=1) as resp:
                data = json.loads(resp.read())
                with ceiling_lock:
                    # OR-merge: if either poll caught a trigger, keep it
                    # until the bridge's /state consumer clears it
                    for i in range(2):
                        if data['ir'][i]:
                            ceiling_ir[i] = 1
                    ceiling_alive = True
        except:
            ceiling_alive = False
        time.sleep(0.08)


def pop_ceiling_ir():
    """Read and clear the cached IR trigger flags."""
    with ceiling_lock:
        vals = list(ceiling_ir)
        ceiling_ir[0] = 0
        ceiling_ir[1] = 0
    return vals


# ============================================================
#  HTTP HANDLER
# ============================================================

class BridgeHandler(http.server.BaseHTTPRequestHandler):

    def do_GET(self):
        path = self.path.split('?')[0]

        # ── Serve the HTML game ──────────────────────────────
        if path == '/' or path == '/index.html':
            self.serve_html()

        # ── Unified state: 9 floor buttons + 2 ceiling IR ───
        elif path == '/state':
            self.handle_state()

        # ── Floor NeoPixel commands → forward to floor ───────
        elif path in ('/set_tile', '/set_all_tiles', '/set_led',
                       '/clear', '/brightness'):
            self.forward_to_floor()

        # ── Ceiling commands → forward to ceiling ────────────
        elif path in ('/ceiling_state', '/ceiling_event',
                       '/ceiling_speed'):
            self.handle_ceiling_cmd()

        # ── Health / debug ───────────────────────────────────
        elif path == '/status':
            self.handle_status()

        else:
            self.send_response(404)
            self.end_headers()
            self.wfile.write(b'Not Found')

    def do_OPTIONS(self):
        """Handle CORS preflight."""
        self.send_response(200)
        self.send_header('Access-Control-Allow-Origin', '*')
        self.send_header('Access-Control-Allow-Methods', 'GET')
        self.end_headers()

    # ── Serve HTML ────────────────────────────────────────────

    def serve_html(self):
        try:
            with open(HTML_FILE, 'r', encoding='utf-8') as f:
                content = f.read()
            self.send_response(200)
            self.send_header('Content-Type', 'text/html; charset=utf-8')
            self.send_header('Cache-Control', 'no-store')
            self.end_headers()
            self.wfile.write(content.encode('utf-8'))
        except FileNotFoundError:
            self.send_response(500)
            self.end_headers()
            msg = "ERROR: Cannot find '{}'\n".format(HTML_FILE)
            msg += "Make sure bridge.py and your HTML file are in the same folder!"
            self.wfile.write(msg.encode('utf-8'))

    # ── Unified /state ────────────────────────────────────────
    #
    # Returns {"b": [b0..b8, ir_left, ir_right]}
    #   - indices 0–8:  floor grid buttons
    #   - index 9:      ceiling left IR  (BONUS-L)
    #   - index 10:     ceiling right IR (BONUS-R)
    #
    # This keeps the same 11-element array the HTML already
    # expects, so the game code needs zero changes.
    #

    def handle_state(self):
        # 1. Get 9 floor buttons
        floor_buttons = [0] * 9
        try:
            url = "http://{}:{}/state".format(FLOOR_IP, FLOOR_PORT)
            req = urllib.request.Request(url)
            req.add_header('Connection', 'close')
            with urllib.request.urlopen(req, timeout=1) as resp:
                data = json.loads(resp.read())
                floor_buttons = data.get('b', [0]*9)
        except:
            pass

        # 2. Get 2 ceiling IR triggers (from background cache)
        ir = pop_ceiling_ir()

        # 3. Merge into single 11-element array
        merged = floor_buttons + ir
        payload = json.dumps({"b": merged})
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
